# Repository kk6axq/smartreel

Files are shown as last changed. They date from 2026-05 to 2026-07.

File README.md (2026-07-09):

# SmartReel

SmartReel is a smart storage rack for reels of surface-mount electronic
components that works hand-in-hand with [InvenTree](https://inventree.org/),
an open-source inventory management system. The rack is built from one or more
**reel modules**, each a row of slots; every slot senses whether a reel is
present, has an addressable RGB LED to guide the operator, and can be widened by
pulling **dividers**. A touchscreen **HMI** mounted on the rack is the operator's
control panel — it talks to the rack hardware over RS485 and to InvenTree over
HTTPS. InvenTree stays the single source of truth for inventory; SmartReel
records *where* each reel physically lives and lights slots to guide pick and
put-away. The operator scans a reel, the rack lights up, and the inventory
updates itself.

## Project status & disclaimer

This project was developed with substantial AI assistance (using large language
models as a coding and documentation aid). The hardware, firmware, and plugin
have been built and run on real SmartReel hardware, and the core workflows have
been exercised on the bench and in use — but this is **not infallible software**.
It has not been through formal verification or a third-party audit, it almost
certainly contains bugs, and both the code and the docs may be incomplete or
occasionally wrong.

Treat it as a working reference design, not a turnkey product:

- Review the code yourself before relying on it, and read
  [`docs/known-bugs.md`](docs/known-bugs.md) for known limitations.
- **Security:** the HMI currently talks to InvenTree over HTTPS *without*
  certificate verification (`setInsecure()`), so the auth token is exposed to
  on-path attackers. Do not deploy on an untrusted network until certificate
  pinning is in place — see [`docs/known-bugs.md`](docs/known-bugs.md).
- It is provided as-is, with no warranty. You are responsible for validating it
  for your own use, especially anything safety- or inventory-critical.

Issues and pull requests that fix bugs or fill gaps are welcome.

## Repository layout

```
esp32-hmi/         ESP32-S3 touchscreen HMI firmware (C++ / PlatformIO / LVGL)
core-fw/           RP2040 core firmware that drives the reel modules (C++ / PlatformIO)
inventree-plugin/  InvenTree server-side plugin (Python)
pcbs/              KiCad hardware designs
  CorePCB/           Core PCB
  ReelPCB/           reel module PCB
debug-fw/          Bench/debug tooling (not shipped)
  mock-inventree/    FastAPI stand-in for the plugin, used during HMI development
  core-hwtest/       RP2040 hardware bring-up test
  esp32-rs485-pintest/ standalone ESP32 RS485 pin-toggle tool
  inject.py          bench event injector (drives the core test rig over USB)
  sd-assets/         mock QR codes for bench-testing the scan->resolve flow
docs/              Project documentation (start at docs/README.md)
labels/            Printable slot label PDFs (make_labels.py; PDFs git-ignored)
scripts/           Flashing, SD deployment, QR generation helpers
```

## Documentation

The full documentation set lives under [`docs/`](docs/README.md). Start with the
[documentation index](docs/README.md), then dive into the manual chapters:

- [Concept of Operations](docs/manual/01-concept-of-operations.md) — what SmartReel is and the end-to-end workflows.
- [Hardware Structure](docs/manual/02-hardware.md) — rack, Core PCB, reel modules, LEDs, sensors, wiring.
- [Software Structure](docs/manual/03-software-architecture.md) — components, subsystems, and system data flow.
- [API Reference](docs/manual/04-api-reference.md) — the HMI↔plugin HTTP API and the RS485 wire protocol.
- [InvenTree Integration](docs/manual/05-inventree-integration.md) — the plugin, install/config, and the sync model.
- [Operator User Manual](docs/manual/06-operator-manual.md) — task-oriented guide for shop-floor operators.

## Build & flash

**HMI firmware** (`esp32-hmi/`) and **Core firmware** (`core-fw/`) are
[PlatformIO](https://platformio.org/) projects. Build and flash:

```bash
# HMI (ESP32-S3) — requires manual boot mode (hold BOOT, tap RESET, release BOOT)
cd esp32-hmi && pio run
./scripts/flash-hmi.sh

# Core (RP2040) — UF2 dropped onto the BOOTSEL drive
cd core-fw && pio run
./scripts/flash-core.sh
```

The flash scripts locate the boards by USB VID, so the order they are plugged in
does not matter. See [`scripts/`](scripts/) for SD deployment (`deploy-sd.sh`)
and QR generation helpers.

**InvenTree plugin** (`inventree-plugin/`) is a Python plugin installed into an
InvenTree instance. See [`inventree-plugin/README.md`](inventree-plugin/README.md)
for installation, configuration, and the docker dev workflow.

**Mock server** — for HMI development without a live InvenTree, the FastAPI mock
at [`debug-fw/mock-inventree/`](debug-fw/mock-inventree/) serves the same HTTPS
contract as the plugin. See its [README](debug-fw/mock-inventree/README.md).

## Tests

Host-runnable tests (no hardware or InvenTree install needed) live under
[`tests/`](tests/README.md): the shared RS485 frame codec (`cd tests && make`)
and the plugin's pure service logic (`cd inventree-plugin && python3
test_services.py`). The full contract is exercised against a live InvenTree by
`inventree-plugin/test_live.py` and `test_multirack.py`.

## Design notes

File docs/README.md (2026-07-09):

# SmartReel Documentation

SmartReel is a smart electronics-component-reel storage rack that integrates
with [InvenTree](https://inventree.org/) for inventory management. An operator
stores reels of SMT components in physical slots; the rack tracks what is in
each slot, lights slots up to guide picking and put-away, and keeps inventory
in sync with InvenTree.

This directory is the documentation set for the whole project. It is written
against what the code actually does as of June 2026; where older design notes
disagree with the implementation, the implementation wins and the discrepancy
is called out.

## Documentation set (`docs/manual/`)

| Doc | What it covers |
|---|---|
| [Concept of Operations](manual/01-concept-of-operations.md) | What SmartReel is, who uses it, and the end-to-end workflows (commission, stock, pick, put-away, reconcile, firmware update). |
| [Hardware Structure](manual/02-hardware.md) | The rack, Core PCB, reel modules, ports/chaining, LEDs, sensors, HMI display, power, and RS485 wiring. |
| [Software Structure](manual/03-software-architecture.md) | Each software component, its subsystems and responsibilities, and a system-level data-flow diagram. |
| [API Reference](manual/04-api-reference.md) | The HMI↔plugin HTTP API (endpoints, auth, idempotency, rack identity) and the RS485 wire protocol (framing, message types, FW update). |
| [InvenTree Integration](manual/05-inventree-integration.md) | How the plugin works, installation/config, the op-queue + reconcile sync model, online/offline behaviour, and multi-rack. |
| [Operator User Manual](manual/06-operator-manual.md) | Plain-language, task-oriented guide for shop-floor operators using the HMI touchscreen. |

## Reference material (this directory)

These are the working documents the manual was built from. They remain useful
for detail and history but are not the authoritative manual:

- `hmi-plugin-api.md` — original API contract (superseded in detail by
  `manual/04-api-reference.md`, but still the canonical short-form contract).
- `smartreel-rs485-protocol.md` — original RS485 design note. Note its message
  catalog lists firmware messages under category `0xF_`; the **code implements
  them at `0x30`–`0x35`** (see API reference for why).
- `user-stories.md` — the behavioural source of truth for the workflows.
- `known-bugs.md` — open and fixed issues.

## Component layout (repository root)

```
esp32-hmi/         ESP32-S3 touchscreen HMI firmware (C++ / PlatformIO / LVGL)
core-fw/           RP2040 core firmware that drives the reel modules (C++ / PlatformIO)
inventree-plugin/  InvenTree server-side plugin (Python)
pcbs/              KiCad hardware designs
  CorePCB/           Core PCB
  ReelPCB/           reel module PCB
debug-fw/          Bench/debug tooling (not shipped)
  mock-inventree/    FastAPI stand-in for the plugin, used during HMI development
  core-hwtest/       RP2040 hardware bring-up test
  esp32-rs485-pintest/ standalone ESP32 RS485 pin-toggle tool
  inject.py          bench event injector (drives the core test rig over USB)
  sd-assets/         mock QR codes for bench-testing the scan->resolve flow
labels/            Printable slot label PDFs (make_labels.py; PDFs git-ignored)
scripts/           Flashing, SD deployment, QR generation helpers
```

> **In-progress areas.** Two features were being developed alongside this
> documentation: an HMI graphics/tearing refinement, and a plugin "locate"
> capability for the find-a-part flow. The find/locate behaviour is described
> in the ConOps and InvenTree sections but may still be evolving.
</content>
</invoke>

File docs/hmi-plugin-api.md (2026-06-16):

# SmartReel HMI ↔ InvenTree plugin API (v1)

Canonical contract between the SmartReel HMI and the SmartReel InvenTree
plugin. Two servers implement it:

- `inventree-plugin/` — the real thing, running inside InvenTree.
  Base URL: `https://<inventree-host>/plugin/smartreel`
- `debug-fw/mock-inventree/` — standalone FastAPI mock for bench development.
  Base URL: `https://<dev-host>:8443`

The HMI appends `/api/v1/<path>` to its configured base URL, so both
servers are reached identically. Behaviour is specified by
`docs/user-stories.md` — when this file and the user stories disagree,
the user stories win and this file is out of date.

## Conventions

- **Auth**: every endpoint except `GET /health` requires
  `Authorization: Token <token>`. The real plugin accepts InvenTree API
  tokens; the mock uses `SR_TOKEN` (default `dev-token`).
- **HTTPS only**: the HMI refuses to send the token over cleartext.
- **Idempotency**: every mutating request carries an `op_id` string
  (`hmi-<chip-id>-<millis>-<n>`). Servers cache `op_id → response` for
  ≥10 minutes and replay the cached response on retry.
- **Slot numbers are physical positions** (1..N). The HMI's logical
  slots (divider-combined) map to the anchor physical position of the
  reel. InvenTree models each physical slot as a structural
  sub-location of the rack location, so a part shows as e.g.
  "SmartReel Rack A / Slot 32".
- **Errors**: non-2xx with `{"detail": "<human-readable>"}`.

## Endpoints

### `GET /health` — liveness (no auth)

```jsonc
{ "ok": true, "server": "smartreel-plugin", "version": "0.2.0", "time": "..." }
```

### `POST /rack/register` — boot-time self-registration

```jsonc
// req
{ "n_slots": 64, "op_id": "..." }
// resp
{ "location_id": 42, "slot_locations": [ { "slot": 1, "location_id": 4201 }, ... ] }
```

Idempotent. Ensures the rack location and one sub-location per physical
slot exist; creates missing ones if `n_slots` grew.

### `GET /rack` — full rack snapshot

Used at boot to sync, and periodically for reconciliation (detecting
stock moved in InvenTree without a physical removal — user-stories.md
"Background: Inventree inventory locations").

```jsonc
{
  "location_id": 42,
  "n_slots": 64,
  "slots": [
    {
      "slot": 3,
      "location_id": 4203,
      "stock": {                  // null when logically empty
        "id": 1001,
        "qty": 5000,
        "batch": "B-241001",
        "barcode": "MOCK-PART-00001",
        "part": { "id": "R-10K-0805", "name": "RES 10kohm 1% 0805",
                  "pkg": "0805", "mfg": "Yageo" }
      }
    }, ...
  ],
  "pickjobs_available": 2,
  "locates": [                    // pending "light this slot" requests
    { "id": 7, "slot_num": 32, "part": "R-10K-0805",
      "part_name": "RES 10kohm 1% 0805", "stock_id": 1001,
      "at": "2026-06-13T12:00:00" }
  ]
}
```

The HMI owns physical truth (slot sensors); this snapshot is logical
truth. A slot that is logically empty but physically occupied means the
part was moved in InvenTree behind our back → the HMI lights that slot
and instructs the user to remove the reel (no inventory action on
removal — InvenTree already moved it).

`locates` carries pending **locate requests** (see "Locate from InvenTree"
below): each is a slot the HMI should light to draw attention to it. The
HMI lights `locates[].slot_num` and, once shown, acks the ids via
`POST /rack/locates/ack` so they don't re-appear on the next poll.

### `POST /barcode/resolve` — what did I just scan?

```jsonc
// req
{ "code": "<raw scanned string>", "op_id": "..." }
// resp
{
  "type": "stockitem" | "part" | "location" | "unknown",
  "stock": { ...same shape as rack snapshot stock, plus "slot_num": 3|0... },
  "part":  { ... },              // when type == "part"
  "message": "Unknown barcode"   // when type == "unknown"
}
```

The real plugin resolves through InvenTree's barcode framework, so any
QR InvenTree can print (StockItem labels included) resolves here, as do
custom codes linked to a stock item at receival (matched by barcode
hash). In practice most scans are InvenTree-generated StockItem QR
labels — supplier codes are often 1D/Datamatrix, which the SmartReel
scanner doesn't read.
`stock.slot_num` is non-zero when that stock item is already in a rack
slot ("already in slot N" UX).

### `POST /rack/slots/{n}/assign` — load a reel into a slot

```jsonc
// req
{ "stock_item_id": 1001, "op_id": "..." }
// resp
{ "slot": 3, "stock": { ... } }
// errors: 404 unknown slot/stock, 409 slot occupied
```

Transfers the stock item into the slot's sub-location (with audit
trail). If the item was in another rack slot, that slot is implicitly
freed. Completes user story 1 after the HMI detects physical placement.

### `POST /rack/slots/{n}/pick` — single pick (whole reel)

```jsonc
// req
{ "op_id": "...", "destination_id": null }   // destination optional
// resp
{ "slot": 3, "stock_id": 1001, "moved_to": 99 }
// errors: 404 unknown slot, 409 slot logically empty
```

**Whole-reel semantics** (user story 3): transfers the slot's
StockItem to `destination_id` if given, else the plugin's configured
Staging location. The slot is then logically empty. No quantity math —
the reel physically left the rack.

### `POST /rack/slots/{n}/clear` — reconcile a manual removal

```jsonc
// req
{ "op_id": "...", "reason": "anomaly:removed" }
// resp
{ "slot": 3, "stock_id": 1001, "moved_to": 98 }
```

For anomaly paths (reel yanked without a scan/pick). Stock moves to the
configured "Unsorted / pulled" location so it isn't lost. 2xx even if
the slot was already logically empty (idempotent goal state).

### `POST /rack/locates/ack` — acknowledge consumed locate requests

```jsonc
// req
{ "ids": [7, 8] }        // ack these ids; {} or {"ids": []} clears the queue
// resp
{ "locates": [ ...remaining locate requests... ] }
```

Drains locate requests the HMI has lit (see "Locate from InvenTree").
Idempotent by construction: acking an unknown/already-acked id is a no-op.

### `GET /pickjobs` — list pick jobs

Jobs are created in InvenTree from build orders (plugin panel "Send to
SmartReel" on the Build Order page — user story 4).

```jsonc
{
  "jobs": [
    {
      "id": "BO-0042",
      "name": "PCB-Rev-A x 5",
      "requested_at": "2026-06-11T14:02:00Z",
      "status": "pending" | "partial" | "done",
      "destination_id": 99,            // staging unless overridden at send time
      "items": [
        {
          "idx": 0,
          "part_id": "R-10K-0805",
          "part_name": "RES 10kohm 1% 0805",
          "qty": 250,                  // required qty, informational on the HMI
          "picked": false,
          "located_slots": [3, 17]     // rack slots currently holding this part
        }, ...
      ]
    }, ...
  ]
}
```

- An **item** is one part. The HMI lights `located_slots` for all
  unpicked items; removing a reel of that part from any lit slot picks
  the item (one reel per item).
- `status` is **derived server-side**: `pending` (nothing picked),
  `partial` (some picked), `done` (all picked). The HMI's cancel button
  is purely local — already-picked items stay picked and the job shows
  `partial`, resumable later (user story 4, partial-pick paragraph).
- Items whose part is not in the rack have `located_slots: []`; the HMI
  shows them as unfulfillable rather than hiding them.

### `POST /pickjobs/{id}/items/{idx}/pick` — pick one job item

```jsonc
// req
{ "slot_num": 3, "op_id": "..." }
// resp
{ "item": { ...updated item... }, "job_status": "partial" | "done" }
// errors: 404 job/item/slot, 409 slot doesn't hold the item's part,
//         409 item already picked
```

Validates the slot holds the item's part, performs a whole-reel pick to
the job's destination, marks the item picked.

### `POST /anomaly` — report sensor-detected anomalies

```jsonc
// req
{ "kind": "removed" | "added" | "divider",
  "slot_num": 12, "detail": "free text", "op_id": "..." }
// resp
{ "id": 7, "logged": true }
```

Audit log on the server side (the real plugin attaches a note/history
entry). Inventory correction is separate (`/clear`).

### `GET /parts/locate?part_id=R-10K-0805`

```jsonc
{ "part_id": "R-10K-0805", "slots": [3, 17] }
```

Powers "find this part" independent of pick jobs.

## Locate from InvenTree (web-UI "locate" button → light a slot)

InvenTree's web UI has a **locate** button on StockItem and StockLocation
pages. The plugin implements InvenTree's `LocateMixin`
(`locate_stock_item` / `locate_stock_location`); InvenTree offloads the
call to a background worker, and the plugin — which has no direct link to
the rack — records the request as a pending locate on the owning rack and
lets the HMI light the slot. Flow:

```
InvenTree "locate" button
  → POST /api/plugin/locate/   (InvenTree core)
  → offload_task → SmartReelPlugin.locate_stock_item / _location  (worker)
  → resolve item/location → (rack, physical slot_num)
  → enqueue locate on the rack's metadata
        │
HMI  ── GET /rack (its existing poll) ──► sees `locates: [{id, slot_num,…}]`
  → lights slot_num
  → POST /rack/locates/ack {ids:[…]}  ──► request drained
```

- `locate_stock_item(item_pk)`: if the item is in stock and homed in a
  rack slot, queues that slot (carrying the part/stock context).
- `locate_stock_location(location_pk)`: if the location is a rack **slot**,
  queues that slot; if it's a **rack** itself, queues every occupied slot;
  locations outside any SmartReel rack are a no-op (some other plugin owns
  them).
- A locate for an already-queued slot **refreshes** it (no duplicate
  stacking); the queue is capped (50) and stored on the rack location's
  `metadata['smartreel_locates']`.
- Locate requests are **not** op_id-idempotent (they originate inside
  InvenTree, not from the HMI); the HMI side is made safe by `ack`'s set
  semantics and by the per-slot dedupe.

## Provisioning (how the HMI gets its URL + token)

Typing on the HMI is painful, so credentials are delivered by QR code
using the scanner that's already on the unit:

1. In InvenTree, the SmartReel plugin settings panel shows a **setup
   QR code** (and a button to regenerate it / revoke the old token).
   The token is an InvenTree API token issued for a dedicated machine
   user, so SmartReel access can be revoked independently.
2. On the HMI: Settings → Network → "Scan setup code" → scan the
   screen. The HMI parses the payload, stores URL + token in
   `config_store`, and immediately runs `GET /health` to confirm.

QR payload (one line of text):

```jsonc
SRPROV1:{"u":"https://inventree.example/plugin/smartreel",
         "t":"inv-token-...",
         "f":"AB:CD:..."}   // optional TLS cert SHA-256 fingerprint
```

- `SRPROV1:` prefix distinguishes a provisioning code from a part
  barcode (and versions the payload).
- `u` is the plugin base URL (HMI appends `/api/v1/...`).
- `f` is optional; when present the HMI may pin the server cert
  instead of blind-trusting it. Ignored by firmware that doesn't pin.

The mock prints an equivalent QR/payload from its dashboard so bench
provisioning works the same way.

## Plugin settings (real plugin)

| Setting | Meaning |
|---|---|
| Rack location | structural location representing this SmartReel unit |
| Staging location | default destination for picked reels |
| Pulled location | destination for anomaly `/clear` removals |

## Multiple SmartReel units

Supported. One InvenTree instance drives many independent racks, and the
HMI/wire protocol is unchanged because each unit's identity rides on its
API token.

- Each rack is its own `StockLocation` tagged
  `metadata['smartreel'] = { "is_rack": true, "staging"?, "pulled"? }`;
  slots are child locations tagged `{"slot": n}`.
- **The token carries the rack.** Provisioning (`GET /provision?location=
  <pk>`) tags the location a rack and binds the issued `ApiToken` via
  `token.set_metadata('smartreel_rack', <loc_pk>)`. Every rack-scoped
  request resolves its rack from `request.auth`; an unbound token is
  refused with 409 (re-provision). There is no global "rack location"
  setting and no shared-rack fallback — every unit, including the first,
  is provisioned from its location page.
- `/health` and `/barcode/resolve` are rack-independent (resolve only
  uses the rack to fill `slot_num`).
- Pick jobs store a target rack pk; `GET /pickjobs` and `located_slots`
  are scoped to the requesting token's rack. A build can carry **one job
  per rack**: the panel lists candidate reels (`GET /pickjobs/options`) and
  `POST /pickjobs/from-build` takes `stock_ids`, grouping the selected reels
  by the rack that holds them (each item pinned to its `stock_id`).
  `GET /pickjobs?all=1` (session) lists every rack's jobs for the panel, and
  `GET /racks` lists configured racks.
- The provisioning panel appears on every stock-location page.
  `STAGING_LOCATION` / `PULLED_LOCATION` are instance-wide defaults a
  rack may override in its own metadata.

## Changelog

- **2026-06-15**: review-feedback round. Added `GET /rack/occupancy` (cheap
  fingerprint for ~10s move detection) and `GET /pickjobs/options` (candidate
  reels per BOM line). `POST /pickjobs/from-build` now takes `stock_ids` and
  fans out **one job per rack** (each item pinned to a `stock_id`) instead of a
  single `rack_location_id` job; `DELETE /pickjobs/{id}` clears all of a build's
  rack jobs.
- **2026-06-13**: LocateMixin support — InvenTree's web-UI "locate" button
  (StockItem / StockLocation) now lights the slot on the physical rack.
  Locate requests ride on the `GET /rack` snapshot (`locates`) and are
  drained by `POST /rack/locates/ack`. Mock gains a `POST /_dev/locate`
  helper to simulate the button.
- **2026-06-13**: multiple racks implemented — rack identity is bound to
  the HMI's API token; the global `RACK_LOCATION` setting and single-rack
  fallback are removed. Added `/racks`, `rack_location_id` on
  `from-build`, and `/pickjobs?all=1` for the panel.
- **2026-06-11**: rewritten against `docs/user-stories.md`. Picks are
  whole-reel transfers (qty decrement model removed); pick jobs come
  from build orders with derived `pending/partial/done` status; rack
  snapshot doubles as the reconciliation source; `destination_id`
  per job/pick.

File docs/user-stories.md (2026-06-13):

# User Stories
This doc explains how Smart Reel is going to be used. The goal is that this will help hone the direction of development.

## Background
The user uses Inventree to manage electronic components for PCB Assembly in a small to medium sized business or hobby environment. They use Inventree to streamline inventory management, and use plugins to automate monotonous tasks. For the sake of SmartReel, we're mostly concerned with reels of SMT components. Each reel in their library is individually labelled with a QR code that's associated with the Inventree StockItem.

## Background: Inventree inventory locations
Each SmartReel instance is configured as a structural inventory location in Inventree. Each slot is a sub location of the parent reel location, and when parts are stored, they are transferred into slot locations. This way, a user can lookup a part and see that it's in "SmartReel Rack A, Slot 32."

It's possible (though not recommended) that a part could be moved in Inventree without being removed from SmartReel first. If this happens, the SmartReel should alert the user so that the next time a user is present, the offending part(s) can be manually removed. This would work by lighting up the offending parts and instructing the user to remove them.

## Use case 1: storing parts
When the user receives new parts they've ordered, they inventory them into Inventree. This gets them into inventory, but they need to be properly stored. To do this, they walk up to the SmartReel HMI, then scan the reel's QR code, or clicks the load button on the screen and scans the QR code on the reel.

When this happens, the SmartReel instance uses its connection to Inventree via the SmartReel plugin to get basic info about the part, showing on the screen the name of the part and the current qty. It then follows the loading flow to direct the user to load it into a slot (see the loading flow section). Once placed, it moves that StockItem in Inventree to be housed in that slot location.

## Use case 2: browsing parts
The HMI has a view screen that lets you scroll through parts that are in the SmartReel unit. Each entry has a find button that when pressed lights up the LEDs for that slot for a period of a few seconds. There is also a pick button that triggers a single pick action.

## User case 3: single part picking
When a user wants to retrieve a single reel from SmartReel, they go to the view screen, find the part in the list, then click pick. The system then lights up the LED corresponding to that part's location. At any time prior to the part being removed the user can cancel the action by clicking a cancel button on the HMI. Once the user picks up the reel, the button is no longer pressed, and the system registers the inventory removal. This causes the reel StockItem to be transferred to a predetermined inventory location, i.e. "Staging" in Inventree. This location is configured in the Inventree plugin. Once complete, it turns off the LED and the slot is now logically empty.

## User case 4: job picking
When the user has a build order for parts in Inventree, they can open the SmartReel plugin and send a pick job. This basically provides the smart reel unit a "job" which is a series of parts that need to be picked. The user can then go to the jobs screen in the HMI, select the job, and the unit will light up all the parts that need to be picked. Once all the parts are picked, the job is complete and all the parts are transferred (to the staging location or another specificed location).

If the user only picks some of the parts, or none of the parts, and presses the cancel button, then only the parts (if any) that were removed are moved in inventory. The user can come back to finish the pick job later (it should show partially picked).

## SmartReel hardware
SmartReel is composed of reel modules. These have a button for each slot that is pressed whenever a reel is present in the slot. Additionally there are dividers that can be removed to make slots wider, to accomodate larger reels. Each divider has a button that is pressed when the divider is present. This allows SmartReel to automatically know the width of slots (single width, double, multi, etc), and the presence of parts. Each slot also has an addressable RGB led. This is used to indicate slot status during various actions. When a composite slot is formed, all of the LEDs for the individual slots in that group all follow the same state together. Like if a slot needs to light up red and there's three slots in the composite slot, all three LEDs should be red.

## SmartReel Loading
This details exactly how loading works from a user interaction perspective. Once the HMI is ready to load, it lights up the LEDs for any slots that are not currently occupied. These are potential locations for the user to place the part. The user can cancel the loading operation at any time prior to inserting the parts by clicking cancel on the HMI. Once they place the reel of parts into a slot, the HMI detects the button being pressed and registers that location as the location of that part. The part is now "placed" and the loading action is complete, and inventory records can be updated.

## Internet connectivity
The HMI needs internet connectivity to connect to Inventree and the SmartReel plugin. If internet is not present, the user should be warned, and we should try to re-establish a connection. For now, we won't support picking if access to Inventree isn't available, to prevent the Smartreel from getting out of sync with Inventree.

## UI Updates
A last few notes on improving the UI.
The current screen has very small font. It's only a 4.3" screen, so we should prioritize less, larger font size text. The current reel occupancy grid that takes up the top 1/3 of the home screen should move to its own screen. We should try to keep all font sizes at least as large as what we have for the main card titles on the home screen. The current small font size is too small.

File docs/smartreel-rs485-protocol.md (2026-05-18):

# SmartReel RS485 Protocol & Firmware Update Design
SmartReel — Project Context
A modular system of "smart reels" managed from a touchscreen HMI. Each reel module has addressable LEDs and a row of inputs; the HMI controls the lighting and reacts to input events.
Hardware architecture
Three boards, one cable run:

HMI — ESP32 with touchscreen + SD card. Acts as RS485 bus master. User interface, configuration storage, firmware images for the core, any network connectivity.
Core PCB — RP2040 or RP2350 ("Pico"). Talks to up to 4+ reel modules. Hosts the RS485 transceiver (SP3485), 3.3V↔5V level shifters (74AHCT244 / 74LVC244), and a 12V→5V buck for the reel rail.
Reel modules — pluggable. Each carries WS2812B LEDs, a 74HC165 PISO shift register for inputs, and a sense resistor/ID network read by the core's ADC.

ESP32 HMI ↔ RP2040/RP2350 core, RS485 link, four reel modules with WS2812B LEDs and PISO shift registers.

## Frame format

Length-prefixed frame with CRC-16. Avoids the timing dependencies of Modbus RTU and is easier to debug:

```
+------+------+------+------+------+------+------+--------------+------+------+
| 0xAA | 0x55 | LEN_H| LEN_L| ADDR | SEQ  | TYPE | PAYLOAD ...  | CRC_H| CRC_L|
+------+------+------+------+------+------+------+--------------+------+------+
```

- **0xAA 0x55** — sync bytes; receiver hunts for these to resync after a glitch.
- **LEN** — number of bytes from ADDR through end of PAYLOAD (excludes sync and CRC). 16-bit lets you do larger firmware chunks comfortably.
- **ADDR** — slave address (0x01 for the core; reserve 0x00 broadcast, 0xFF for the ESP32-as-master). Useful if you ever bus more than one core, or for a "scan for devices" probe.
- **SEQ** — sequence number; a response echoes the request's SEQ so the ESP32 can match them and detect retransmits.
- **TYPE** — high nibble = category (0=system, 1=reel I/O, 2=LED, 3=config, 8=async event, F=firmware update); low nibble + payload define the specific command. Lets you parse/dispatch by category cheaply.
- **CRC-16/CCITT** over ADDR..end-of-PAYLOAD. CRC-16/CCITT-FALSE (poly 0x1021, init 0xFFFF) is fine and trivially available on both sides.

Replies use the same TYPE byte with bit 7 set (so 0x10 request → 0x90 response), with bit 6 indicating error (so 0xD0 = error response). That makes the wire trace readable without a decoder table.

## Application message catalog

### System (TYPE 0x0_)

| Code | Name | Dir | Payload |
|---|---|-----|---|
| 0x00 | PING | E→P | none → echo |
| 0x01 | GET_VERSION | E→P | none → fw_major, fw_minor, fw_patch, build_id (4B), hw_rev |
| 0x02 | GET_STATUS | E→P | none → uptime_s (4B), reels_present (bitmap), error_flags (2B) |
| 0x03 | RESET | E→P | reason byte (0=normal, 1=enter_update_mode) |
| 0x04 | POLL | E→P | none → "no events" or up to N queued events |

### Reel I/O (TYPE 0x1_)

| Code | Name | Dir | Payload |
|---|---|-----|---|
| 0x10 | GET_REEL_INFO | E→P | reel_id (or 0xFF for all) → presence, sense_mv (2B per reel), eeprom/ID bytes |
| 0x11 | READ_INPUTS | E→P | reel_id → PISO bytes (whatever your shift register reads) |
| 0x12 | SET_POLL_RATE | E→P | reel_id, rate_hz (2B) — how often the Pico samples PISO |

### LED control (TYPE 0x2_)

| Code | Name | Dir | Payload |
|---|---|-----|---|
| 0x20 | SET_REEL_PIXELS | E→P | reel_id, start_idx, count, R,G,B,R,G,B,... |
| 0x21 | FILL_REEL | E→P | reel_id, R, G, B |
| 0x22 | SET_BRIGHTNESS | E→P | reel_id (or 0xFF), brightness (0–255) |
| 0x23 | SET_ANIMATION | E→P | reel_id, anim_id, params... (chase, pulse, etc — runs locally on Pico) |
| 0x24 | COMMIT | E→P | reel_bitmap — atomic show of staged pixel data across multiple reels |

The COMMIT pattern is worth doing: SET_REEL_PIXELS writes to a back-buffer, COMMIT flips and calls `show()` across all selected reels in the same frame. Otherwise your reels visibly tear when updating more than one at a time over a slowish bus.

### Async events (TYPE 0x8_, Pico → ESP32, no response expected)

| Code | Name | Payload |
|---|---|---|
| 0x80 | INPUT_CHANGE | reel_id, prev_state, new_state, timestamp_ms (4B) |
| 0x81 | REEL_INSERTED | reel_id, sense_mv (2B), ID bytes |
| 0x82 | REEL_REMOVED | reel_id |
| 0x83 | SENSE_THRESHOLD | reel_id, sense_mv, threshold_id |
| 0x8F | LOG | level, ASCII message |

Events are fire-and-forget — but the ESP32 should NAK with an "unknown SEQ" if it gets a spurious one, so the Pico knows the link is alive. Pico keeps a small ring buffer of unACK'd events and resends after a timeout; mark them with a sequence number the ESP32 echoes back in an ACK frame.

This is important: **on a half-duplex RS485 link, the Pico cannot transmit whenever it wants**. The ESP32 is bus master. So async events have to be either (a) returned in the response slot of the next poll, or (b) signaled via a dedicated "any events pending?" poll the ESP32 issues regularly. The simplest pattern: the ESP32 issues `POLL` (0x04) every ~20ms, and the Pico's response is either "no events" or up to N queued events. Higher-priority button events should keep latency under ~50ms; this poll rate gets you there.

## Firmware update

Run a custom bootloader on the Pico and lay out flash as A/B slots so you always have a known-good fallback.

### Flash layout (RP2040, 2 MB)

```
0x10000000  Bootloader            (32 KB)
0x10008000  Metadata block        (4 KB, two copies for wear)
0x1000A000  App Slot A            (~1000 KB)
0x10104000  App Slot B            (~1000 KB)
0x101FE000  Reserved / config     (8 KB)
```

On RP2350 (4 MB) you have headroom to make each slot 1.5 MB and add a scratch staging area if you want, but the A/B pattern is the same.

### Metadata block

Contains: active slot, pending slot, image size, SHA-256, version, boot count, "needs confirm" flag. Write two copies and pick the one with the higher monotonic counter — cheap protection against power-loss during update.

### Bootloader logic

On reset, read metadata, pick the slot marked active, verify its hash if `needs_confirm == true`, jump to it. If the previously-booted slot failed to clear the `needs_confirm` flag within N boots, revert to the other slot. This is the rollback guarantee.

### Update flow over RS485

| Step | Message | Notes |
|---|---|---|
| 1 | `FW_BEGIN` | ESP32 sends total_size (4B), SHA-256 (32B), version (4B). Pico picks inactive slot, erases it (this takes a few seconds — respond with `BUSY` until done, then `READY`). |
| 2 | `FW_CHUNK` × N | offset (4B) + data (up to ~512B per frame). Pico writes to flash, ACKs with the offset it last wrote. ESP32 retries any unACK'd chunk. |
| 3 | `FW_VERIFY` | Pico re-reads the slot, hashes it, compares to the announced hash. Returns OK or hash-mismatch. |
| 4 | `FW_COMMIT` | Pico writes metadata: pending=new_slot, needs_confirm=true. ACKs, then issues itself a reset. |
| 5 | Bootloader runs | Sees pending slot, boots it, sets boot_count++. |
| 6 | New app boots | Sends `FW_BOOTED` event to ESP32. ESP32 sends `FW_CONFIRM`, which clears `needs_confirm`. Without this confirm within a deadline, next reset reverts to the previous slot. |

The confirm-after-boot step is what saves you when the new firmware boots but is broken in a way that crashes before it can talk to the HMI — you ship a unit, update over the wire, the new firmware has a bug that bricks RS485, and on the next power cycle the bootloader rolls back automatically.

### Practical numbers

- At 115200 baud, raw throughput is ~11 KB/s; a 500 KB image takes ~50 s plus erase/verify overhead. Bump to 921600 baud (SP3485 handles it fine over short cable runs) and you're at ~6 s.
- Chunk size: 256 B is the RP2040 flash page size. Send one or two pages per RS485 frame so the Pico can write a whole page without buffering. With 512 B chunks + framing overhead, you get ~80% bus efficiency.
- During update, suspend reel polling and LED animations — the Pico shouldn't be doing PIO work while it's erasing flash anyway (XIP is disabled, interrupts off).

### Entering update mode

Two options:

1. The running app handles `FW_BEGIN` itself (writing to the *other* slot while it runs from its own), which is the smoothest UX.
2. The ESP32 sends `RESET` with reason=enter_update_mode, the bootloader sees a flag in metadata, and runs a minimal RS485 update handler instead of jumping to the app.

The first is preferable because the user gets reel functionality up until the moment of commit; the bootloader fallback is your insurance for when the app is too broken to even handle FW messages.

One last thing — keep the bootloader *small* and *boring*. No reel logic, no LEDs, no animations. Just RS485 receive, flash write, metadata, jump. That bootloader is the thing you can never field-update, so it has to be obviously correct.

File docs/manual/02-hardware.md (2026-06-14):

# SmartReel — Hardware Structure

This describes the physical/electrical structure of a SmartReel rack. Details
come from the firmware configuration, board READMEs, and the KiCad project file
names; where a value couldn't be confirmed from text sources it is marked TODO.

## 1. Overview

A rack is three kinds of board on one cable run:

```
  +-----------------------+        +------------------+        +-----------------------------+
  |  HMI                  |        |  Core PCB        |        |  Reel modules (per port)    |
  |  ESP32-S3 +           | RS485  |  RP2040/RP2350   | ports  |  WS2812B LEDs               |
  |  4.3" RGB touchscreen |<------>|  bus slave       |<======>|  74HC165 input registers    |
  |  + SD card            |        |  bus master-side |  0..3  |  slot + divider buttons     |
  |  (RS485 master)       |        |  to modules      |        |  sense/ID resistor network  |
  +-----------------------+        +------------------+        +-----------------------------+
```

- The **HMI** is the RS485 bus master and the user interface.
- The **Core PCB** is the RS485 slave; it drives up to 4 ports of reel modules.
- **Reel modules** are pluggable and chain off each port (up to 4 deep).

Capacity ceiling: **4 ports × 4 modules/port × 16 slots/module = 256 slots**.

## 2. HMI — ESP32-S3 touchscreen

Board: **Waveshare ESP32-S3-Touch-LCD-4.3B**.

| Item | Detail |
|---|---|
| MCU | ESP32-S3-WROOM-1-N16R8 (16 MB flash, 8 MB PSRAM), 240 MHz |
| Display | 4.3", 800×480, 16-bit RGB565 parallel (DPI), ST7262-class timing |
| Pixel clock | 16 MHz (12 MHz causes a stuck-white panel on this board — do not lower) |
| Touch | GT911 capacitive, I²C (addr 0x5D/0x14), INT on GPIO4 |
| I/O expander | CH422G on I²C (addr 0x24) — drives LCD reset, backlight, touch reset, USB select |
| Storage | microSD via SDMMC, **1-bit** mode (CMD GPIO11, CLK GPIO12, D0 GPIO13) |
| RS485 | UART, **auto-direction** transceiver — TX GPIO44, RX GPIO43, no DE pin |
| I²C bus | SDA GPIO8, SCL GPIO9, 400 kHz (shared by GT911, CH422G, optional QR scanner) |
| QR scanner | optional I²C device (addr 0x0C); if absent the HMI falls back to manual entry |

RGB LCD pin map (from `esp32-hmi/src/board/board_pins.h`):

```
HSYNC GPIO46   VSYNC GPIO3   DE GPIO5   PCLK GPIO7
R[0..4] GPIO 1,  2, 42, 41, 40
G[0..5] GPIO 39, 0, 45, 48, 47, 21
B[0..4] GPIO 14, 38, 18, 17, 10
```

The display uses **two framebuffers in PSRAM** (~768 KB each, ~1.5 MB total)
for tearing-free refresh; see [Software Architecture](03-software-architecture.md#display).

> **RS485 direction asymmetry.** The HMI side uses a hardware *auto-direction*
> transceiver (no driver-enable GPIO), and the firmware caps the link at
> **115200 baud** because the auto-direction RC switch cannot turn the line
> around fast enough for higher rates. The Core side (below) uses a discrete DE
> pin. Both ends run 115200.

## 3. Core PCB

KiCad project: `pcbs/CorePCB/SmartReelCore/`.

| Function | Part / detail |
|---|---|
| MCU | Raspberry Pi Pico class — **RP2040 or RP2350** |
| RS485 transceiver | SP3485 (half-duplex) with a discrete DE/RE# line |
| Level shifting | SN74AHCT244 / 74LVC244 (3.3 V ↔ 5 V) for the module signals |
| Module rail | 12 V → 5 V buck converter feeding the reel modules |
| Sense ADC | ADS1115 (16-bit I²C, 4 channels — one per port) for module detection |

Core pin assignments (from `core-fw/src/config.h`):

```
RS485:   TX GP16 -> SP3485 DI     RX GP17 <- SP3485 RO     DE GP18 -> SP3485 DE+RE#
RS485 baud: 115200
LED data (NeoPXL8): GP6, GP7, GP8, GP9  (ports 0..3)
Shift registers (74HC165), shared:  clock GP10,  latch/PL# GP11 (active LOW)
Shift-register data in, per port:   GP12, GP13, GP14, GP15
Sense ADC: ADS1115 on I²C0 (SDA GP0/SCL GP1 area — TODO confirm exact I²C pins), addr 0x48
Debug LED: GP2 (RS485 link health)
```

The Core is RS485 slave address **0x01**. It declares the link "up" only while a
valid master frame has arrived within the last 1000 ms.

## 4. Reel modules

KiCad project: `pcbs/ReelPCB/` (with a `Switch_Unit.kicad_sch` sub-circuit and
per-module label PDFs under `labels/`).

Each module provides **16 reel slots** and carries:

- **16 WS2812B addressable RGB LEDs** — one per slot, daisy-chained. Driven from
  the Core via NeoPXL8 (PIO + DMA, 8 parallel data lines, 800 kHz, GRB order).
- **Inputs via 74HC165 PISO shift registers** — **32 input bits per module**:
  - 16 **slot-present** bits (a button pressed while a reel sits in the slot), and
  - 16 **divider** bits (a button pressed while the divider to the *right* of a
    slot is installed).
  - Logical bit order per module is `D0 S0 D1 S1 … D15 S15`. (The raw hardware
    clocks slots out reversed within each shift-register byte; the Core firmware
    descrambles them, so the rest of the system sees the clean order.)
- **Sense / ID resistor network** — a per-module pull-down that the Core reads on
  that port's ADS1115 channel to count how many modules are chained.

### Dividers and slot width

Dividers between slots are removable. Pulling the divider between two slots
merges them into one wider logical slot (for a larger reel). Because each
divider has a sense bit, the rack automatically knows the width of every slot.
When several physical slots form one composite slot, all of their LEDs follow
the same colour/state together.

### Module-count detection

Each inserted module adds a 10 kΩ pull-down in parallel against a 2.2 kΩ
pull-up to 3.3 V, so the rail voltage on a port quantises by module count. The
Core firmware maps the measured millivolts to a module count (0–4):

| Modules | Approx. sense (mV) |
|---|---|
| 0 (open) | 3300 |
| 1 | 1458 |
| 2 | 989 |
| 3 | 732 |
| 4 | 579 |

A change must hold for 2 consecutive samples before the Core emits a
`REEL_INSERTED`/`REEL_REMOVED` event.

## 5. Ports and chaining

- The Core has **4 ports** (0–3). In the protocol, `reel_id` **is the port
  number**.
- Each port carries one LED data line, one shift-register chain (shared clock +
  latch, per-port data line), and one sense channel.
- Up to **4 modules chain per port**. Within a port, module `m` owns LED pixels
  `[m*16, m*16+16)` and input bits `[m*32, m*32+32)`.
- The HMI labels ports as "chains" 1–4 in the UI.

## 6. Power

- **12 V** input is the main rail. The Core PCB bucks it to **5 V** for the reel
  module rail (LEDs + logic). Reel modules use 5 V and 3.3 V (3.3 V generated on
  the Core / modules — TODO confirm exact per-module regulation).
- **HMI power**: the Waveshare board is typically powered over USB-C or a 5 V
  input. The exact rack-integration power source is TODO (not documented in the
  source tree).

## 7. RS485 wiring

A single RS485 pair runs between the HMI (master) and the Core (slave). The Core
fans the reel modules out over its ports; the module signals (LED data,
shift-register clock/latch/data, sense) are *not* RS485 — they are local
parallel/serial lines level-shifted on the Core PCB. Only the HMI↔Core link is
RS485.

- Master address `0xFF`, Core address `0x01`, broadcast `0x00`.
- 115200 baud, half-duplex. The HMI polls the Core every ~20 ms so button
  events reach the UI within ~50 ms.

See the [API Reference](04-api-reference.md#part-b-rs485-wire-protocol) for the
full frame format and message catalog.

## 8. Supporting artifacts in the repo

- `labels/` — printable slot-label PDFs (one per module, slots numbered).
- `scripts/` — flashing, SD deployment, and mock-QR generation helpers.
- `debug-fw/inject.py` — bench event injector for the RP2040 core test rig.
- `debug-fw/sd-assets/` — mock QR codes for bench-testing the scan flow.
- `pcbs/CorePCB/`, `pcbs/ReelPCB/` — the KiCad designs (schematics, PCB, production
  outputs under each project's `production/`).

## 9. Known hardware TODOs

- Exact ADS1115 I²C pin assignment on the Core (config comment vs. board).
- Per-module 3.3 V regulation source.
- HMI power input in the final rack integration.
- Real-hardware validation of the module-count sense thresholds.
</content>

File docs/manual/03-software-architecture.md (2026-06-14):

# SmartReel — Software Architecture

Four software components make up SmartReel. Two run on the rack (the HMI and
Core firmware), one runs inside InvenTree (the plugin), and one is a development
stand-in for the plugin (the mock).

## 1. System-level data flow

```mermaid
flowchart LR
    subgraph Rack
        HMI["ESP32-S3 HMI firmware<br/>(C++ / LVGL)"]
        CORE["RP2040 Core firmware<br/>(C++)"]
        MODS["Reel modules<br/>LEDs + sensors"]
    end
    subgraph Server
        PLUGIN["SmartReel plugin<br/>(Python, inside InvenTree)"]
        INV["InvenTree core<br/>StockItems / Locations / Builds"]
    end
    MOCK["debug-fw/mock-inventree<br/>(FastAPI, dev only)"]

    HMI <-->|"RS485 framed protocol<br/>115200 baud, half-duplex"| CORE
    CORE <-->|"LED data + shift-reg inputs + sense"| MODS
    HMI <-->|"HTTPS /api/v1/*<br/>Token auth, op_id idempotency"| PLUGIN
    PLUGIN --> INV
    HMI -.->|"same HTTPS contract<br/>(bench dev)"| MOCK
```

Two protocols, two boundaries:

- **HMI ↔ Core**: a custom length-prefixed, CRC-16 framed protocol over RS485.
  The HMI is master and polls the Core; the Core reports sensor events and
  drives the LEDs. See [API Reference, Part B](04-api-reference.md#part-b-rs485-wire-protocol).
- **HMI ↔ InvenTree**: a workflow-shaped HTTPS API (`/api/v1/*`) with Token
  auth and `op_id` idempotency. The plugin (or the mock) serves it. See
  [API Reference, Part A](04-api-reference.md#part-a-hmi--plugin-http-api).

## 2. ESP32-S3 HMI firmware (`esp32-hmi/`)

C++ on PlatformIO (pioarduino / IDF 5.3), LVGL 8.4, ArduinoJson 7. Source is
organised by subsystem under `src/`.

### Subsystems

| Subsystem | Responsibility |
|---|---|
| `app/` | Application state and logic: logical-slot model, hardware mirror, LED orchestration, and the InvenTree sync engine. |
| `board/` | Pin map (`board_pins.h`) and the CH422G I/O-expander driver. |
| `display/` | RGB LCD driver and the tearing-free framebuffer pipeline. |
| `touch/` | GT911 capacitive touch driver → LVGL input device. |
| `sensors/` | Optional I²C QR scanner. |
| `rs485/` | RS485 master: frame codec, CRC-16, transactions, background poll. |
| `fw/` | Firmware update: HMI self-OTA from SD, and Core OTA over RS485. |
| `net/` | WiFi manager and the `inv_api` HTTPS client to InvenTree. |
| `storage/` | `config_store` (settings/credentials) and `state_store` (slot contents, jobs) on SD. |
| `ui/` | LVGL screens, the app-state model, screen manager, theme. |
| `util/` | Helpers, including marshalling work onto the LVGL task. |

### Key modules

**`app/inv_sync`** — owns *all* InvenTree traffic. A worker task
(`inv-sync`, priority 1, pinned to APP_CPU) runs a:

- **Health poll** — every 15 s while online, 5 s while offline; sets
  `app_state.online`. "Online" means the last good health check is younger than
  45 s.
- **Rack register** on first successful contact.
- **Reconcile** — `GET /rack` every 60 s and on demand; compares server truth
  to physical sensors (see [ConOps §4.5](01-concept-of-operations.md#45-inventory-reconcile-background)).
- **Pick-job fetch** on demand (throttled ~10 s).
- **Op queue** — a 16-deep retrying queue of mutations (`Assign`, `Pick`,
  `JobPick`, `Clear`, `Anomaly`). Each op carries a unique `op_id`; the queue
  retries up to 20 attempts. A `4xx` is a permanent reject (logged; the next
  reconcile catches any drift). Idempotency makes retries safe.

**`app` state & slot model** (`ui/app_state.h`, `app/slot_map`, `app/hw_mirror`):

- `hw_mirror` is the live cache of per-port module counts and per-module 32-bit
  input words, fed by RS485 poll events.
- `slot_map` is pure logic that turns module counts + divider bits into
  **logical slots**: runs of physical slots merged across pulled dividers,
  numbered by the lowest physical position in the run.
- `app_state` holds the current logical rack (slot → part/qty/state). States:
  `EMPTY`, `OCCUPIED`, `TARGET` (lit for an action), `PICKED`, `WARN`, `ERROR`.
- **Commissioning**: before commit the rack follows live hardware; after commit
  (`rack.committed`) the HMI validates live hardware against the committed
  layout and raises anomalies on deviation.

**`net/inv_api`** — the HTTPS client (details in
[API Reference](04-api-reference.md)):

- Appends `/api/v1/<path>` to the configured base URL.
- **HTTPS-only**: `build_url()` refuses any non-`https://` URL, so the token
  never crosses the wire in cleartext.
- Sends `Authorization: Token <token>`.
- Generates op_ids of the form `hmi-<chip-id>-<millis>-<n>`.
- 4 s request timeout, 2 s connect timeout. Calls are blocking; callers run them
  on a worker task and marshal results back to the LVGL task.
- TLS currently uses `setInsecure()` (self-signed mock); cert pinning (the `f`
  field in the provisioning payload) is parsed but not yet enforced — **TODO**.

**`rs485/`** — the master side of the wire protocol. Frame codec with sync bytes
`0xAA 0x55`, 16-bit length, ADDR/SEQ/TYPE, CRC-16/CCITT-FALSE. A background poll
task issues `POLL` every ~20 ms, pulls queued Core events, dispatches them, and
ACKs them. A single bus mutex serialises transactions.

**`fw/`** — `fw_update` streams an HMI app image from SD into the inactive OTA
partition (Arduino Update), then reboots. `fw_core_update` pushes an RP2040
image to the Core over RS485 in 512-byte chunks with SHA-256 verification.

**`display/`**  — RGB LCD at 800×480, 16 MHz pixel clock,
two driver-managed framebuffers in PSRAM. To eliminate tearing, the driver
follows the Waveshare "avoid-tearing" pattern: LVGL renders into the inactive
framebuffer and the flush callback blocks on a vsync semaphore before swapping,
so the panel never scans a half-written frame. The RGB DMA runs on **PRO_CPU**;
all application work (LVGL, inv_sync) is pinned to **APP_CPU** at priority 1 —
any load on PRO_CPU causes visible tearing.

> An HMI graphics/tearing refinement was in progress alongside this
> documentation; the exact tearing-mode details in `display.cpp` may have
> shifted. The principle (vsync-gated double-buffer swap, app work off PRO_CPU)
> holds.

### UI screens (`ui/screens/`)

| Screen | Purpose |
|---|---|
| Home | 5 large action tiles: Load, View, Pick, Rack, Settings. |
| Load | Scan a reel QR, see part details, place into a lit empty slot. |
| View | Browse slots; Find (flash LED) and Pick per part. |
| Rack (dot grid) | Occupancy grid across all ports, colour-coded by state. |
| Pick (list) | Active pick jobs; partial jobs show Resume. |
| Pick (active) | The selected job's items with per-item progress. |
| Settings | Network, firmware update, self-test, slot/divider commissioning. |
| Settings → Network | WiFi + InvenTree URL/token, *Scan setup code* provisioning. |
| Settings → Self-test | Button/LED/reel diagnostics. |
| Settings → Firmware | HMI/Core versions, SD image picker, update. |
| Settings → Slots / Dividers | Commission module counts and divider layout. |

Fonts were deliberately enlarged for the 4.3" screen (the dot grid moved off
Home onto its own Rack screen; "Configure" was renamed "Settings").

### Threading model (summary)

| Task | CPU | Priority | Role |
|---|---|---|---|
| LVGL | APP | 2 | UI refresh, state mutation, event dispatch |
| inv_sync | APP | 1 | health poll, reconcile, op queue |
| rs485 poll | (app) | — | pull Core events every ~20 ms |
| state_store writer | — | — | periodic SD flush of dirty slots/jobs |

All InvenTree calls and RS485 transactions are blocking and run off the LVGL
task; results are posted back via a "dispatch on LVGL" helper.

## 3. RP2040 Core firmware (`core-fw/`)

C++ on PlatformIO (arduino-pico). The Core is the RS485 slave that drives the
reel modules. It is production firmware: `reel_id` = port (0–3), 1–4 chained
modules per port, 32 input bits per module, NeoPXL8 PIO-driven LEDs.

Responsibilities:

- **Serve the RS485 protocol** as a slave at address 0x01: respond to system,
  reel-I/O, LED, and firmware messages; answer the master's ~20 ms `POLL` with
  any queued events.
- **Sample inputs** at 100 Hz (10 ms), 2-sample debounce, and emit
  `INPUT_CHANGE` events when slot/divider bits change.
- **Sample sense** per port (~10 Hz/channel) and emit `REEL_INSERTED` /
  `REEL_REMOVED` when the module count changes.
- **Drive LEDs** via NeoPXL8 with a staging/commit pattern so multi-port updates
  show atomically (no tearing across strips).
- **Handle firmware updates**: stage a new image (Arduino-pico Updater), verify
  SHA-256, commit, and reboot; the OTA bootloader provides A/B rollback.
- **Queue events** in a 32-slot ring with sequence numbers; resend un-ACK'd
  events on each poll (because on a half-duplex bus the slave cannot transmit
  whenever it wants).

Key config (`core-fw/src/config.h`): `N_PORTS=4`, `MAX_MODULES_PER_PORT=4`,
`MODULE_LEDS=16`, `MODULE_INPUT_BITS=32`, `RS485_BAUD=115200`.

## 4. InvenTree plugin (`inventree-plugin/smart_reel/`)

Python plugin (version 0.2.0, slug `smartreel`). Layered:

```
core.py       plugin class: settings, URL routes, web panels
api.py        DRF views — thin HTTP layer, op_id idempotency, auth/error mapping
services.py   domain logic against InvenTree models (StockItem.move, metadata)
static/panel.js   the two web panels (Build Order + provisioning)
```

Mixins: `UrlsMixin` (custom routes under `/plugin/smartreel/`),
`SettingsMixin` (Staging/Pulled location settings + optional HMI URL),
`UserInterfaceMixin` (web panels). Barcode resolution goes through InvenTree's
barcode plugin registry. See [InvenTree Integration](05-inventree-integration.md)
for the full picture (rack identity, sync model, multi-rack).

## 5. Mock InvenTree (`debug-fw/mock-inventree/`)

A FastAPI service that implements the same `/api/v1/*` contract so the HMI can
be developed without a live InvenTree. Serves HTTPS on `:8443` (self-signed
cert under `certs/`), token `dev-token` by default, with the same `op_id`
idempotency (10-minute cache). It also serves a dashboard and a
`GET /_dev/provision` endpoint that prints the `SRPROV1:` payload + QR. It is
single-rack; multi-rack lives only in the real plugin. See
[InvenTree Integration §6](05-inventree-integration.md#6-the-mock-server).

## 6. Where the components agree on the contract

The HMI, the real plugin, and the mock all speak the identical
`/api/v1/*` contract. `docs/user-stories.md` is the behavioural source of
truth; `docs/hmi-plugin-api.md` plus
[API Reference](04-api-reference.md) document the wire shapes.
</content>

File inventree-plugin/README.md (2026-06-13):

# inventree-smart-reel

InvenTree plugin for the SmartReel smart reel holder.

Implements the HMI ↔ plugin contract from `docs/hmi-plugin-api.md` (repo
root) under `/plugin/smartreel/api/v1/…`, plus two web-UI panels:

- **Build Order page → "SmartReel" panel** — send the build's BOM to the
  rack as a pick job, watch per-item progress, remove/resend.
- **Rack location page → "SmartReel HMI" panel** — provisioning QR
  (`SRPROV1:` payload with URL + dedicated API token). Scan it from the
  HMI instead of typing credentials.

## Structure

```
smart_reel/
  core.py       # plugin class: settings, URL routes, UI panels
  api.py        # DRF views (thin HTTP layer, op_id idempotency)
  services.py   # domain logic against InvenTree models
  static/panel.js  # both web panels (no build step)
```

## Multiple racks

One instance drives many independent SmartReel units. Each rack is its
own StockLocation tagged `metadata['smartreel'] = {"is_rack": true}`;
provisioning binds the issued API token to that rack
(`token.metadata['smartreel_rack']`), so the HMI's token alone tells the
plugin which rack it's driving — no HMI/wire change. An unbound token is
refused (409). Provision each rack from its stock-location page → the
"SmartReel HMI" panel. `./test-multirack.sh` covers rack isolation.

## Behaviour notes

- **Slots** are StockLocation children of a rack location, carrying
  `metadata['smartreel'] = {'slot': n}`; created/grown by
  `POST /rack/register` (which targets the token's rack).
- **Picks are whole-reel** `StockItem.move()` transfers (audit-trailed) to
  the staging location — no quantity math.
- **Pick jobs** live in the source Build's `metadata['smartreel']`
  (with a target rack pk); job status is derived
  (`pending`/`partial`/`done`).
- **Anomalies** append to the rack location's
  `metadata['smartreel_anomalies']` (capped at 200).

## Settings (InvenTree → Settings → Plugins → Smart Reel)

| Setting | Meaning |
|---|---|
| Staging location | default destination for picked reels (per-rack override via metadata) |
| Pulled location | destination for anomaly-cleared reels (per-rack override via metadata) |

Racks are not a setting — provision each from its stock-location page.

InvenTree must have **plugin URL integration enabled**
(`ENABLE_PLUGINS_URL`) for the API to be reachable.

## Dev install

Installed (editable) into the local InvenTree docker instance at
`~/Desktop/Projects/inventree/` — see the README there for the
mount/reload workflow. Restart `inventree-server` + `inventree-worker`
after code changes. `./test-live.sh` exercises the full contract against
that instance.

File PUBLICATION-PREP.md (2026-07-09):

# Publication prep checklist

Working tracker for the pre-publication review pass (delete before final public push,
or keep as a record — your call). Generated 2026-06-25.

## Blockers (must fix before posting)
- [x] Add MIT LICENSE file at repo root (copyright holder = "Lukas Severinghaus" — change to Freefly Systems if that's the correct owner)
- [x] Credentials → env vars: `set-hmi-url.sh`, `test_live.py`, `test_multirack.py`
- [x] Internal network names → placeholders: `app_state.cpp`, `config_store.cpp`, `dev-restart.sh` (also location_id 42→0)
- [x] Fix stale broken `set-hmi-url.sh` `/provision` call (now takes optional rack-pk arg)

## Correctness bugs
- [x] `core-fw/src/main.cpp` — require successful `FW_VERIFY` before `FW_COMMIT` (new `s_fw_verified` gate)
- [x] `esp32-hmi/src/net/wifi_mgr.cpp` — WiFi event callback now marshals online state via `dispatch_on_lvgl`
- [x] `inventree-plugin/smart_reel/api.py` — `token.set_metadata(...)` moved inside `transaction.atomic()`
- [x] `inventree-plugin/smart_reel/services.py` — `enqueue_locate` now locks the rack row (`select_for_update`)

## Docs cleanup
- [x] Removed `docs/review-feedback.md`, `docs/review-feedback-solutions.md`, `docs/test-plan.md`
- [x] Fixed the `test-plan.md` reference in `docs/README.md`

## Unit tests
- [x] RS485 frame/protocol codec host tests (`tests/`, `make`) — 67 checks pass
- [x] Plugin `services.py` pytest suite (`inventree-plugin/test_services.py`) — 10 tests pass

## Done earlier
- [x] README AI disclaimer + security note added; Tests section added

## NOT done (out of scope for this pass — flagged for your call)
- [ ] TLS `setInsecure()` in `inv_api.cpp:92` — still disabled; now disclaimed in README + known-bugs. Implement cert pinning before untrusted-network deployment.
- [ ] Rename misleading `mock_*` state mutators in `app_state.cpp` (production code, not test scaffolding).
- [ ] 30+ `// review item N/R/B` code comments reference the now-removed `docs/review-feedback.md`; harmless but orphaned.
- [ ] `inv_api.h:5` header comment says "HTTP or HTTPS"; runtime is HTTPS-only.
- [ ] `core-fw` symlinked shared headers won't materialize on a default Windows `git clone` — worth a build note.
- [ ] Firmware was NOT recompiled here (no PlatformIO toolchain/hardware in this environment); edits are minimal/surgical — build before flashing.
- [ ] Confirm copyright holder in LICENSE / `pyproject.toml` author email before publishing.

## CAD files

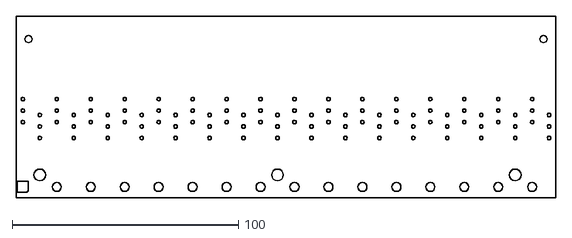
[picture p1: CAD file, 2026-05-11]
pcbs/ReelPCB/Smart Reel-PCB-Tiled-2026-05-07 15-32-16.dxf
238.5 x 80.0

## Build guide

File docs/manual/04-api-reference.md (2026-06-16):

# SmartReel — API Reference

Two interfaces are documented here:

- **Part A — the HMI ↔ plugin HTTP API** (`/api/v1/*` over HTTPS), implemented
  identically by the InvenTree plugin and the development mock.
- **Part B — the RS485 wire protocol** between the HMI and the Core firmware.

This builds on `docs/hmi-plugin-api.md` and `docs/smartreel-rs485-protocol.md`
and is reconciled against the code. Where the code differs from the older docs
it is flagged.

---

## Part A — HMI ↔ plugin HTTP API

### A.1 Base URL and routing

- Real plugin: `https://<inventree-host>/plugin/smartreel`
- Mock: `https://<dev-host>:8443`

The HMI appends `/api/v1/<path>` to its configured base URL, so both servers
are reached identically.

### A.2 Conventions

- **Auth** — every endpoint except `GET /health` requires
  `Authorization: Token <token>`. The real plugin accepts InvenTree API tokens;
  the mock compares against `SR_TOKEN` (default `dev-token`).
- **HTTPS only** — the HMI refuses to send the token over cleartext; non-HTTPS
  base URLs are rejected client-side.
- **Idempotency** — every mutating request carries an `op_id` string,
  `hmi-<chip-id>-<millis>-<n>`. The server caches `op_id → response` for
  **10 minutes** and replays the cached response on retry. The HMI's op queue
  retries until success precisely because this makes retries safe.
- **Slot numbers are physical positions** (1..N). Each maps to an InvenTree
  structural sub-location of the rack location, so a part shows as
  e.g. "SmartReel Rack A / Slot 32".
- **Rack identity rides on the token** — see [A.5](#a5-rack-identity--multi-rack).
- **Errors** — non-2xx with `{"detail": "<human-readable>"}`. Status mapping in
  the plugin: `404` not found, `409` conflict (slot occupied / logically empty /
  unbound token), `400` bad request, `403` not staff (provision).

### A.3 Endpoints

#### `GET /health` — liveness (no auth)
```jsonc
{ "ok": true, "server": "smartreel-plugin", "version": "0.2.0", "time": "..." }
```
Marked auth-exempt server-side. The HMI polls this to set its online/offline
state.

#### `POST /rack/register` — boot-time self-registration
```jsonc
// req
{ "n_slots": 64, "op_id": "..." }
// resp
{ "location_id": 42, "slot_locations": [ { "slot": 1, "location_id": 4201 }, ... ] }
```
Idempotent. Ensures the rack location and one sub-location per physical slot
("Slot 01"…"Slot NN", tagged `metadata['smartreel']={'slot':n}`); creates
missing ones if `n_slots` grew. Rack is resolved from the token.

#### `GET /rack` — full rack snapshot
Used at boot and for periodic reconciliation. Doubles as the reconcile source
(detecting stock moved in InvenTree without a physical removal).
```jsonc
{
  "location_id": 42,
  "n_slots": 64,
  "slots": [
    {
      "slot": 3,
      "location_id": 4203,
      "stock": {                  // null when logically empty
        "id": 1001,
        "qty": 5000,
        "batch": "B-241001",
        "barcode": "MOCK-PART-00001",
        "part": { "id": "R-10K-0805", "name": "RES 10kohm 1% 0805",
                  "pkg": "0805", "mfg": "Yageo" }
      }
    }, ...
  ],
  "pickjobs_available": 2
}
```

#### `GET /rack/occupancy` — cheap occupancy fingerprint
```jsonc
{ "rev": "9f2a1c0b4d7e6f81" }
```
An opaque hash over the rack's slot occupancy (+ pending locates). The HMI polls
this every ~5s and runs the full `GET /rack` reconcile only when `rev` changes,
so a reel moved out of a slot in InvenTree is detected within ~10s without a full
snapshot each poll (item 6). Compare for equality only; the value is not stable
across server versions.

#### `POST /barcode/resolve` — what did I just scan?
```jsonc
// req
{ "code": "<raw scanned string>", "op_id": "..." }
// resp
{
  "type": "stockitem" | "part" | "location" | "unknown",
  "stock": { ...same shape as rack snapshot stock, plus "slot_num": 3|0 ... },
  "part":  { ... },              // when type == "part"
  "message": "Unknown barcode"   // when type == "unknown"
}
```
The real plugin resolves through InvenTree's barcode plugin registry, so any QR
InvenTree can print (including StockItem labels) resolves. `stock.slot_num` is
non-zero when the item is already in a rack slot. Rack is optional here (only
used to fill `slot_num`).

#### `POST /rack/slots/{n}/assign` — load a reel into a slot
```jsonc
// req
{ "stock_item_id": 1001, "op_id": "..." }
// resp
{ "slot": 3, "stock": { ... } }
// errors: 404 unknown slot/stock, 409 slot occupied by a different item
```
Transfers the StockItem into the slot's sub-location (audit trail via
`StockItem.move()`). If the item was in another rack slot, that slot is
implicitly freed.

#### `POST /rack/slots/{n}/pick` — single pick (whole reel)
```jsonc
// req
{ "op_id": "...", "destination_id": null }   // destination optional
// resp
{ "slot": 3, "stock_id": 1001, "moved_to": 99 }
// errors: 404 unknown slot, 409 slot logically empty
```
**Whole-reel semantics**: the StockItem moves to `destination_id` if given,
else the configured **Staging** location, and the slot becomes logically empty.
No quantity math.

#### `POST /rack/slots/{n}/clear` — reconcile a manual removal
```jsonc
// req
{ "op_id": "...", "reason": "anomaly:removed" }
// resp
{ "slot": 3, "stock_id": 1001, "moved_to": 98 }
```
Moves the slot's stock to the configured **Pulled** location. Returns 2xx even
if the slot was already empty (idempotent goal state).

#### `GET /pickjobs` — list pick jobs
```jsonc
{
  "jobs": [
    {
      "id": "BO-0042",
      "name": "PCB-Rev-A x 5",
      "requested_at": "2026-06-11T14:02:00Z",
      "status": "pending" | "partial" | "done",
      "destination_id": 99,
      "items": [
        {
          "idx": 0,
          "part_id": "R-10K-0805",
          "part_name": "RES 10kohm 1% 0805",
          "qty": 250,                  // required qty, informational on the HMI
          "picked": false,
          "located_slots": [3, 17]     // rack slots currently holding this part
        }, ...
      ]
    }, ...
  ]
}
```
- One **item** = one part. Removing a reel of that part from any lit slot picks
  the item (one reel per item).
- `status` is **derived server-side**: `pending` / `partial` / `done`.
- Without query args, returns only the requesting token's rack's jobs (HMI use).
  With `?all=1` (session auth) returns every rack's jobs (web panel).
- Items whose part isn't in the rack have `located_slots: []`.

#### `POST /pickjobs/{id}/items/{idx}/pick` — pick one job item
```jsonc
// req
{ "slot_num": 3, "op_id": "..." }
// resp
{ "item": { ...updated item... }, "job_status": "partial" | "done" }
// errors: 404 job/item/slot, 409 slot doesn't hold the item's part / already picked
```
Validates the slot holds the item's part, performs a whole-reel pick to the
job's destination, marks the item picked.

#### `GET /pickjobs/options?build_id={id}` — candidate reels for a build
```jsonc
{
  "lines": [
    {
      "part": 12, "part_id": "R-10K-0805", "part_name": "RES 10kohm 1% 0805",
      "qty": 250,
      "candidates": [
        { "stock_id": 1001, "qty": 5000, "batch": "A",
          "rack_id": 7, "rack_name": "Rack A", "slot_num": 3 }, ...
      ]
    }, ...
  ]
}
```
Web-panel endpoint (session auth). For each BOM line, every in-stock reel of
that part that lives in **any** SmartReel rack — what the panel's reel picker
offers (item 10a).

#### `POST /pickjobs/from-build` — create jobs from a Build Order
```jsonc
// req
{ "build_id": 42, "stock_ids": [1001, 1002], "destination_id": null, "op_id": "..." }
// resp
{ "jobs": [ { ...job object (rack A)... }, { ...job object (rack B)... } ] }
```
Web-panel endpoint (session auth). The selected reels are grouped by the rack
that holds them, creating **one job per rack** (item 10b); each job item is
pinned to its `stock_id`, so only that reel's slot lights. Replaces any prior
SmartReel jobs on the build.

#### `DELETE /pickjobs/{id}` — remove a build's jobs
```jsonc
{ "deleted": "BO-0042" }
```
Clears every rack's job for the build.

#### `GET /racks` — list configured racks (web panel)
```jsonc
{ "racks": [ { "location_id": 7, "name": "SmartReel Rack A", "n_slots": 64 }, ... ] }
```

#### `GET /parts/locate?part_id=R-10K-0805` — find a part
```jsonc
{ "part_id": "R-10K-0805", "slots": [3, 17] }
```
Powers "find this part" independent of pick jobs, scoped to the token's rack.
`part_id` may be an IPN or a pk string.

> The locate capability was being refined alongside this documentation (a
> possible "locate mixin" on the plugin). The `GET /parts/locate` query above is
> the current implementation; the area may evolve.

#### `POST /anomaly` — report sensor-detected anomalies
```jsonc
// req
{ "kind": "removed" | "added" | "divider", "slot_num": 12,
  "detail": "free text", "op_id": "..." }
// resp
{ "id": 7, "logged": true }
```
Audit log on the rack location's metadata (capped at 200 entries). Inventory
correction is separate (`/clear`).

#### `GET /provision?location=<pk>[&rotate=1]` — provision a rack (staff only)
Session-authenticated, staff only. Tags the location as a rack, mints/rotates an
API token bound to it, and returns the setup payload + QR:
```jsonc
{ "payload": "SRPROV1:{...}", "svg": "<svg>...", "token_name": "smartreel-rack-7",
  "base_url": "https://inventree.example/plugin/smartreel", "rack": { ... } }
```

### A.4 Provisioning payload (`SRPROV1:`)

Delivered as a QR so credentials don't have to be typed on the HMI:
```jsonc
SRPROV1:{"u":"https://inventree.example/plugin/smartreel",
         "t":"inv-token-...",
         "f":"AB:CD:..."}   // optional TLS cert SHA-256 fingerprint
```
- `SRPROV1:` prefix versions the payload and distinguishes it from a part
  barcode.
- `u` — plugin base URL (HMI appends `/api/v1/...`).
- `t` — InvenTree API token (or `dev-token` from the mock).
- `f` — optional cert fingerprint for pinning. **Parsed by the HMI but not yet
  enforced** (cert pinning is TODO; the HMI currently does not verify the TLS
  cert).

On the HMI: Settings → Network → *Scan setup code* → scan the screen. The HMI
stores URL + token and immediately runs `GET /health`.

### A.5 Rack identity & multi-rack

- Every rack is its own InvenTree `StockLocation` tagged
  `metadata['smartreel'] = {"is_rack": true, "staging"?, "pulled"?}`. Slots are
  child locations tagged `{"slot": n}`.
- **The token carries the rack.** Provisioning binds the issued API token to the
  location via `token.set_metadata('smartreel_rack', <loc_pk>)`. Every
  rack-scoped request resolves its rack from `request.auth`. An **unbound token
  is refused with 409** — re-provision. There is **no global rack setting** and
  no shared-rack fallback; every unit, including the first, is provisioned from
  its location page.
- `/health` and `/barcode/resolve` are rack-independent (resolve only uses the
  rack to fill `slot_num`).
- Pick jobs store a target rack pk; `GET /pickjobs` and `located_slots` are
  scoped to the requesting token's rack. `POST /pickjobs/from-build` takes
  `stock_ids` and fans out one job per rack. `GET /pickjobs?all=1` and `GET /racks` are for
  the web panel.

### A.6 Differences from `docs/hmi-plugin-api.md`

The code matches that contract closely. Notable points confirmed in code:

- Multi-rack is fully implemented (v0.2.0); the global `RACK_LOCATION` setting is
  gone — only `STAGING_LOCATION` and `PULLED_LOCATION` (instance-wide defaults,
  per-rack overridable in metadata) plus an optional HMI-URL setting remain.
- The op_id cache TTL is **600 s (10 minutes)**, matching the doc's "≥10
  minutes".
- The plugin issues the provisioning token for the staff user performing the
  provisioning (named `smartreel-rack-<pk>`); there is no separate fixed
  `smartreel-hmi` machine user baked into the plugin code.

---

## Part B — RS485 wire protocol

Between the HMI (bus master, address `0xFF`) and the Core (slave, `0x01`).
Constants below are from `esp32-hmi/src/rs485/rs485_proto.h` and
`core-fw/src/config.h`; both ends share the same frame codec.

### B.1 Frame format

```
+------+------+------+------+------+------+------+--------------+------+------+
| 0xAA | 0x55 | LEN_H| LEN_L| ADDR | SEQ  | TYPE | PAYLOAD ...  | CRC_H| CRC_L|
+------+------+------+------+------+------+------+--------------+------+------+
```

- **Sync** `0xAA 0x55` — receiver hunts for these to resync after a glitch.
- **LEN** — big-endian 16-bit; counts ADDR through end of PAYLOAD (minimum 3).
- **ADDR** — `0x00` broadcast, `0x01` Core, `0xFF` master (ESP32).
- **SEQ** — request/response matching; a response echoes the request's SEQ.
- **TYPE** — bit 7 set = response (`0x10` request → `0x90` response); bit 6 set
  = error response (`0xD0`). Low 6 bits are the command code.
- **CRC** — CRC-16/CCITT-FALSE (poly `0x1021`, init `0xFFFF`, no reflect, no
  final XOR) over ADDR..end-of-PAYLOAD.
- **MAX_PAYLOAD** = 768 bytes; max frame 777 bytes.
- **Baud** = 115200, half-duplex.

### B.2 Message catalog (request codes)

#### System (0x0_)
| Code | Name | Dir | Notes |
|---|---|---|---|
| 0x00 | PING | E→C | echo |
| 0x01 | GET_VERSION | E→C | → major, minor, patch, build_id(4B), hw_rev |
| 0x02 | GET_STATUS | E→C | → uptime_s(4B), reels_present bitmap, error_flags(2B) |
| 0x03 | RESET | E→C | reason byte (0=normal, 1=enter_update_mode) |
| 0x04 | POLL | E→C | → "no events" or queued events (see B.4) |
| 0x05 | ACK_EVENTS | E→C | count + seq bytes; clears ACK'd events |

#### Reel I/O (0x1_)
| Code | Name | Dir | Notes |
|---|---|---|---|
| 0x10 | GET_REEL_INFO | E→C | reel_id (or 0xFF all) → per-port present, sense_mv, module_count |
| 0x11 | READ_INPUTS | E→C | reel_id → module_count + 4B input word per module |
| 0x12 | SET_POLL_RATE | E→C | reel_id, rate_hz(2B) |

`reel_id` is the **port** number (0–3). Each module's 32-bit input word is laid
out `D0 S0 D1 S1 … D15 S15` (D = divider, S = slot-present).

#### LED control (0x2_)
| Code | Name | Dir | Notes |
|---|---|---|---|
| 0x20 | SET_REEL_PIXELS | E→C | reel_id, start_idx, count, RGB… (stages to back buffer) |
| 0x21 | FILL_REEL | E→C | reel_id, R, G, B (stages + commits) |
| 0x22 | SET_BRIGHTNESS | E→C | reel_id (or 0xFF), brightness 0–255 |
| 0x23 | SET_ANIMATION | E→C | reel_id, anim_id, params (runs on the Core) |
| 0x24 | COMMIT | E→C | reel_bitmap — atomic `show()` across selected ports |

The stage-then-COMMIT pattern avoids visible tearing when updating multiple
ports in one frame.

#### Firmware update (0x3_)
| Code | Name | Dir | Notes |
|---|---|---|---|
| 0x30 | FW_BEGIN | E→C | total_size(4B), SHA-256(32B), version(4B) |
| 0x31 | FW_CHUNK | E→C | offset(4B) + data (512B); → bytes_received(4B) |
| 0x32 | FW_VERIFY | E→C | Core re-hashes the image; OK or hash-mismatch |
| 0x33 | FW_COMMIT | E→C | commit + self-reset |
| 0x34 | FW_CONFIRM | E→C | clears the "needs confirm" flag after a good boot |
| 0x35 | FW_BOOTED | C→E | event: new image booted |

> **Discrepancy with `docs/smartreel-rs485-protocol.md`.** That note places
> firmware messages in category `0xF_`. The **code uses `0x30`–`0x35`** because
> a `0xF_` code would have both the response (bit 7) and error (bit 6) bits set,
> making firmware requests indistinguishable from error responses on the wire.
> Trust the code: firmware messages are at `0x30`–`0x35`.

#### Async events (0x8_, Core → HMI, delivered in the POLL response)
| Code | Name | Payload |
|---|---|---|
| 0x80 | INPUT_CHANGE | port, module, prev(4B), now(4B), ts_ms(4B) |
| 0x81 | REEL_INSERTED | port, module_count, sense_mv(2B) |
| 0x82 | REEL_REMOVED | port, module_count |
| 0x83 | SENSE_THRESHOLD | port, sense_mv, threshold_id |
| 0x8F | LOG | level, ASCII message |

#### Error codes (first payload byte of an error response)
| Code | Meaning |
|---|---|
| 0x00 | OK |
| 0x01 | unknown command |
| 0x02 | bad payload |
| 0x03 | reel absent |
| 0x04 | busy (e.g. flash erasing) |
| 0x10 | FW hash mismatch |
| 0x11 | FW offset out of range |
| 0x12 | FW wrong state |

### B.3 Polling and half-duplex events

On a half-duplex bus the Core cannot transmit unsolicited. The master issues
`POLL` (0x04) every ~20 ms; the Core answers with up to N queued events. The
Core keeps a **32-slot event ring** with per-event sequence numbers and resends
un-ACK'd events on each poll until the master `ACK_EVENTS` (0x05) clears them.
This keeps button-event latency under ~50 ms while guaranteeing delivery up to
the ring's capacity.

POLL response payload: `count`, then for each event `type, seq, len, data…`.

### B.4 Core firmware update flow

| Step | Message | Notes |
|---|---|---|
| 1 | FW_BEGIN | size + SHA-256 + version; Core stages (erase can take seconds → BUSY) |
| 2 | FW_CHUNK ×N | 512-byte chunks; Core ACKs bytes received; master retries gaps |
| 3 | FW_VERIFY | Core re-hashes, compares to the announced SHA-256 |
| 4 | FW_COMMIT | Core writes metadata (pending slot, needs-confirm) and resets |
| 5 | (bootloader) | A/B bootloader boots the new slot |
| 6 | FW_BOOTED → FW_CONFIRM | new app announces itself; master confirms to lock it in |

If the new firmware never sends `FW_BOOTED`/never gets `FW_CONFIRM`, the
bootloader rolls back to the previous slot on the next reset.
</content>

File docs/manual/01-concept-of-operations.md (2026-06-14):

# SmartReel — Concept of Operations

## 1. What SmartReel is

SmartReel is a smart storage rack for reels of surface-mount electronic
components, designed to work hand-in-hand with InvenTree, an open-source
inventory management system. A physical SmartReel rack is made of one or more
**reel modules**, each providing a row of slots. Every slot:

- senses whether a reel is physically present (a button under the reel),
- has an addressable RGB LED to guide the operator, and
- can be widened by pulling **dividers** between slots to fit larger reels.

A touchscreen **HMI** (Human–Machine Interface) mounted on the rack is the
operator's control panel. The HMI talks to the rack hardware over an RS485
serial link and to InvenTree over HTTPS. InvenTree stays the single source of
truth for inventory; SmartReel records *where* each reel physically lives
("SmartReel Rack A, Slot 32") and guides the operator to the right slot.

The goal is to remove the two annoying parts of bench-stock management:
remembering where a reel is, and keeping the digital inventory in step with the
physical one. The operator scans, the rack lights up, and the inventory updates
itself.

## 2. Who uses it

- **Shop-floor operator / technician** — the everyday user. Stores received
  reels, picks single reels, and works through pick jobs for builds. Interacts
  almost entirely through the HMI touchscreen and a QR scanner. The
  [Operator User Manual](06-operator-manual.md) is written for this person.
- **Inventory / production manager** — works in InvenTree's web UI. Receives
  stock, creates build orders, and sends pick jobs to a rack from the Build
  Order page. Provisions new racks from the InvenTree location page.
- **Installer / maintainer** — sets up a rack: wires it, commissions the slot
  layout on the HMI, provisions it against InvenTree, and performs firmware
  updates.

The target environment is a small-to-medium business or a serious hobbyist
doing PCB assembly, who already runs InvenTree and wants to automate the
monotonous parts of inventory handling.

## 3. The pieces, at a glance

```
   Operator                InvenTree manager
      |                            |
   [touchscreen]              [web browser]
      |                            |
  +-------+   RS485   +--------+   HTTPS   +-----------------------+
  |  HMI  |<--------->| Core   |           |     InvenTree         |
  | ESP32 |           | PCB    |           |  + SmartReel plugin   |
  |  -S3  |           | RP2040 |           +-----------------------+
  +-------+           +--------+
      |                  |
      | HTTPS            | drives reel modules (LEDs + sensors)
      v                  v
  InvenTree         [Reel modules: slots, dividers, LEDs]
```

See the [Software Architecture](03-software-architecture.md) and
[Hardware](02-hardware.md) docs for the full breakdown.

## 4. End-to-end workflows

The behavioural source of truth is `docs/user-stories.md`. The workflows below
describe what actually happens across the HMI, the rack hardware, and InvenTree.

### 4.1 Commissioning a rack

Done once when a rack is installed, and again whenever its physical layout
changes.

1. **Wire and power the rack.** Reel modules chain off the Core PCB's ports;
   the HMI connects to the Core over RS485. (See [Hardware](02-hardware.md).)
2. **Provision against InvenTree.** In InvenTree, open the stock location that
   represents this rack, open the **SmartReel HMI** panel, and click
   *Provision*. The plugin tags that location as a rack, mints a dedicated API
   token bound to it, and shows a **setup QR code** (`SRPROV1:` payload with
   the plugin URL + token).
3. **Scan the setup code on the HMI.** Settings → Network → *Scan setup code*.
   The HMI stores the URL and token and immediately runs a health check. From
   now on the rack's identity rides on its token — no rack number to configure.
4. **Commission the slot layout.** On first power-up the HMI follows the live
   hardware topology it reads from the Core (how many modules are on each port,
   where the dividers are). The installer reviews this in
   Settings → Slots / Dividers and **commits** it. After commit, the HMI
   validates the live hardware against the committed layout and flags any
   deviation as an anomaly.
5. **Register slots with InvenTree.** On first successful contact the HMI calls
   `POST /rack/register`, which creates one InvenTree sub-location per physical
   slot ("Slot 01" … "Slot NN") under the rack location.

> Multiple racks: one InvenTree instance can drive many racks. Each is
> provisioned separately and identified by its own token. There is no global
> "rack number" setting.

### 4.2 Stocking reels (put-away / load)

When new reels arrive, the operator first receives them into InvenTree
normally (so each reel becomes a StockItem with a QR label). Then they store
them physically:

1. Operator walks to the HMI, taps **Load**, and scans the reel's QR code.
2. The HMI sends the scanned code to `POST /barcode/resolve`. InvenTree
   resolves it to the StockItem and returns the part name and quantity. If the
   reel is already recorded in a slot, the HMI says "already in slot N".
3. The HMI shows the part details and lights every **empty** slot as a
   candidate location.
4. The operator drops the reel into any lit slot. The slot's presence sensor
   fires; after a short debounce the HMI registers that slot as the reel's
   home and queues `POST /rack/slots/{n}/assign`. InvenTree moves the StockItem
   into that slot's sub-location (with an audit trail).
5. The slot LED returns to normal; the load is complete.

If the rack is offline, loads against the on-SD offline catalog stay local and
are reconciled later. Operations that change inventory are queued and retried.

### 4.3 Picking a single reel

For grabbing one whole reel.

1. Operator taps **View**, scrolls to the part (or uses *Find*, which flashes
   the slot LEDs for a few seconds), and taps **Pick**.
2. The HMI lights that slot. The operator can tap **Cancel** any time before
   removing the reel.
3. The operator lifts the reel out. The presence sensor releases; the HMI
   queues a **whole-reel pick** (`POST /rack/slots/{n}/pick`). InvenTree
   transfers the entire StockItem to the configured **Staging** location (or a
   per-pick destination). No quantity math — the whole reel left the rack.
4. The LED turns off; the slot is now logically empty.

Picking is **disabled while the rack is offline** (a banner explains why) to
keep SmartReel from drifting out of sync with InvenTree.

### 4.4 Job picking (kitting a build)

For assembling all the parts a build order needs.

1. In InvenTree, the manager opens a Build Order, opens the **SmartReel**
   panel, picks the target rack, and clicks *Send to SmartReel*. The plugin
   turns the build's BOM into a **pick job** (one item per part) stored on the
   build, scoped to that rack.
2. On the HMI, the operator opens **Pick**, selects the job, and the rack
   lights every slot that holds a part the job still needs.
3. For each item, the operator removes a reel from any lit slot (or taps the
   on-screen *Picked* button). The HMI reports `pickjobs/{id}/items/{idx}/pick`;
   InvenTree marks that item picked and moves the reel to the job's destination.
4. When all items are picked the job is **done** and disappears from the list.
5. **Partial picks resume.** If the operator cancels partway, already-picked
   items stay picked server-side; the job shows as *partially picked* with a
   **Resume** button and can be finished later. Cancel is local-only.

Items whose part isn't currently in the rack are shown as unfulfillable rather
than hidden.

### 4.5 Inventory reconcile (background)

InvenTree is the source of truth, and stock can move there without anyone
touching the rack (e.g. someone transfers a reel's StockItem in the web UI).
SmartReel detects and resolves these drifts:

- Every ~60 seconds (and on demand) the HMI fetches a full rack snapshot
  (`GET /rack`) and compares it to the physical truth from the sensors.
- **Moved in InvenTree but still physically present** → the HMI lights the slot
  amber and shows a "Stock moved in InvenTree" prompt instructing removal.
  Removing the reel resolves it (no inventory action — InvenTree already moved
  it).
- **Logically present but physically absent** (a reel yanked without a pick) →
  the HMI logs an anomaly and clears the slot to the **Pulled** location so the
  stock isn't lost.
- **Both present** → the HMI adopts InvenTree's part/quantity for that slot
  (boot-time sync).

Reconcile is skipped for slots the operator is actively working (a lit pick
target, a just-picked slot) and when the Core hardware mirror is invalid.

### 4.6 Firmware update

Two independent update paths exist (see the [API Reference](04-api-reference.md)
for the wire/partition detail):

- **HMI self-update** — the ESP32-S3 flashes a new application image from a
  file on its SD card into the inactive OTA partition, then reboots into it.
- **Core update over RS485** — the HMI streams a new RP2040 image to the Core in
  512-byte chunks (`FW_BEGIN` → `FW_CHUNK` × N → `FW_VERIFY` → `FW_COMMIT`),
  SHA-256 verified, with an A/B-slot bootloader that rolls back automatically
  if the new image fails to confirm after boot.

## 5. Online / offline philosophy

The HMI continuously health-checks InvenTree (every 15 s while up, every 5 s
while down) and shows an online/offline indicator. The guiding rule:

- **Reads and put-away** degrade gracefully offline (the HMI can show the SD
  offline catalog, and assigns queue for later).
- **Picks are blocked offline** to guarantee the rack never reports a removal
  that InvenTree doesn't know about.
- Every inventory-changing action is queued with an idempotency key (`op_id`)
  and retried until it succeeds, so a flaky network can't lose or double-apply
  a move.
</content>

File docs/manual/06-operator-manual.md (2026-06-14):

# SmartReel — Operator User Manual

A plain-language guide to using the SmartReel touchscreen for everyday work. No
technical background needed. If you're setting up a rack for the first time, see
the [Concept of Operations, Commissioning](01-concept-of-operations.md#41-commissioning-a-rack)
first.

## What SmartReel does for you

SmartReel is a storage rack for component reels with a touchscreen on it. It
remembers which reel is in which slot, lights up the right slot to guide you,
and keeps your InvenTree inventory up to date automatically. You mostly just
**scan, look for the lit slot, and place or pick the reel.**

## The Home screen

The Home screen has five big buttons:

| Button | Use it to… |
|---|---|
| **Load** | Put a new reel into the rack. |
| **View** | Browse what's in the rack, find a part, or pick one reel. |
| **Pick** | Work through a pick job for a build. |
| **Rack** | See the whole rack at a glance (a colour-coded grid of slots). |
| **Settings** | Network setup, firmware updates, diagnostics, slot setup. |

### The online indicator

There's an online/offline indicator on the status bar. When it shows
**online**, everything works. When it shows **offline**, the rack has lost its
connection to InvenTree — see [If the rack is offline](#if-the-rack-is-offline).

### What the slot lights mean

| Light | Meaning |
|---|---|
| Off | Normal occupied or empty slot. |
| Blue | This is your target — place a reel here, or pick from here. |
| Green | Just picked / completed. |
| Amber | Attention: a reel needs to be removed (it was moved in InvenTree). |
| Red | Error with this slot. |

When a slot has been widened by pulling dividers, **all** the LEDs in that wide
slot light up together.

---

## Task: Load a new reel (put-away)

Do this after a reel has been received into InvenTree.

1. Tap **Load** on the Home screen.
2. **Scan the reel's QR code** with the scanner. (No scanner? Tap to enter the
   code by hand.)
3. The screen shows the **part name and quantity**.
   - If it says **"already in slot N"**, that reel is already stored — you're
     done.
4. The rack lights up **every empty slot** in blue. These are your choices.
5. **Drop the reel into any lit slot.** The light turns off and the reel is now
   stored. SmartReel records its location in InvenTree for you.

To back out before placing the reel, tap **Cancel**.

---

## Task: Find a part

1. Tap **View**.
2. Scroll to the part (or search).
3. Tap **Find** next to it. The reel's slot flashes for a few seconds so you can
   spot it.

---

## Task: Pick one reel

1. Tap **View** and find the part.
2. Tap **Pick**. The reel's slot lights blue.
3. **Lift the reel out.** The light turns off and SmartReel records the removal
   in InvenTree (the reel moves to the Staging location).

To stop before removing the reel, tap **Cancel** — nothing changes.

> Picking only works while the rack is **online**. If it's offline, the Pick
> button is disabled and a banner explains why.

---

## Task: Work a pick job (kitting a build)

A pick job is a list of parts someone sent to this rack from a Build Order in
InvenTree.

1. Tap **Pick**. You'll see the available jobs.
   - A job marked **partially picked** has a **Resume** button — you can finish
     it later.
2. Tap a job to open it. The rack lights up **every slot** that holds a part the
   job still needs.
3. For each part:
   - **Lift a reel** from any lit slot for that part, **or**
   - tap the **Picked** button next to the item.
   That item is checked off.
4. When everything is checked off, the job is **done** and disappears.

If you tap **Cancel** partway through, the items you already picked stay picked.
The job shows as *partially picked* and you can come back and Resume it.

Parts that aren't in this rack show up as **unfulfillable** so you know to get
them elsewhere.

---

## Task: See the whole rack

Tap **Rack** for a colour-coded grid of every slot — handy for a quick overview
of what's occupied, empty, or needs attention.

---

## Handling problems

### A slot is lit amber and the screen says "Stock moved in InvenTree"

Someone moved that reel's record in InvenTree without taking the reel out of the
rack. **Remove the reel from the amber slot.** The light clears and everything
is back in sync. (You don't need to scan anything — InvenTree already knows.)

### I pulled a reel without picking it

SmartReel notices a reel that left without a pick, logs it, and moves that stock
to the **Pulled** location in InvenTree so it isn't lost. If you didn't mean to,
re-load the reel with the **Load** flow.

### A slot is red

There's a problem with that slot or its sensor. Try reseating the reel; if it
persists, tell your maintainer and run **Settings → Self-test**.

### If the rack is offline

The online indicator shows **offline** when the rack can't reach InvenTree.
While offline:

- **You can still load reels** (the change is saved and sent automatically once
  the connection comes back).
- **You cannot pick** — this is on purpose, so the inventory never gets out of
  step. The Pick button is disabled.
- SmartReel keeps trying to reconnect on its own. Once it's back online, any
  pending changes are sent automatically.

If it stays offline, check the WiFi/network and the InvenTree connection in
**Settings → Network**.

### Re-connecting / re-provisioning the rack

If credentials need refreshing (e.g. the token was rotated in InvenTree):

1. In InvenTree, open this rack's location page → **SmartReel HMI** panel →
   get the setup QR (rotate the token if needed).
2. On the HMI: **Settings → Network → Scan setup code**, and scan the screen.
   The rack tests the connection right away.

---

## Tips

- **Scan first, then place.** The lit slots only appear after a successful scan.
- **Any lit slot works** for loading — pick whichever is convenient.
- **The reel's presence button is what counts.** SmartReel reacts when you
  physically place or remove a reel, not just when you tap the screen.
- **Wide slots** (dividers pulled) hold larger reels; the whole group lights up
  as one.
- **Cancel is always safe** before you move a reel — it changes nothing.
</content>

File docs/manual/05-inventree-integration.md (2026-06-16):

# SmartReel — InvenTree Integration

How the SmartReel plugin lives inside InvenTree, how to install and configure
it, and the sync model the HMI uses to stay consistent with InvenTree.

## 1. How the plugin works

The plugin (`inventree-plugin/smart_reel/`, slug `smartreel`, v0.2.0) is a
standard InvenTree plugin that exposes a **workflow-shaped HTTP API** the HMI
calls, plus two web-UI panels. It deliberately does **not** proxy InvenTree's
generic REST API; instead it offers exactly the operations the HMI needs
(resolve / register / assign / pick / clear / pickjobs / locate / anomaly /
provision) and translates them into InvenTree model operations. That keeps the
HMI simple.

Layered source:

```
core.py     plugin class — settings, URL routes, UI panels
api.py      DRF views — HTTP layer, op_id idempotency, auth + error mapping
services.py domain logic — StockItem.move(), location/metadata management
static/panel.js  the two browser panels (no build step)
```

Mixins used: `UrlsMixin`, `SettingsMixin`, `UserInterfaceMixin`. Barcode
resolution rides on InvenTree's own barcode plugin registry, so any code
InvenTree can resolve (StockItem QR labels, linked custom codes) resolves here.

### Data model mapping

| SmartReel concept | InvenTree representation |
|---|---|
| A rack | a `StockLocation` tagged `metadata['smartreel']={"is_rack":true, ...}` |
| A slot | a child `StockLocation` of the rack, tagged `{"slot": n}`, named "Slot NN" |
| A reel in a slot | a `StockItem` whose `location` is that slot sub-location |
| A pick job | data stored on a `Build`'s `metadata['smartreel']` |
| An anomaly | an entry in the rack location's `metadata['smartreel_anomalies']` (cap 200) |

All stock movement uses `StockItem.move(destination, reason, user)`, which
creates a `StockHistory` audit entry. **Picks are whole-reel transfers** — the
entire StockItem moves; there is no quantity decrement model.

## 2. Installation and configuration

> Plugin installation follows InvenTree's normal plugin process; confirm
> specifics against the InvenTree version you run.

1. **Install the plugin** into the InvenTree instance (the package's entry point
   is `SmartReelPlugin = "smart_reel.core:SmartReelPlugin"`). Enable it in
   InvenTree's plugin settings.
2. **Enable plugin URLs and the plugin interface** in InvenTree's global
   settings (`ENABLE_PLUGINS_URL`, `ENABLE_PLUGINS_INTERFACE`) so the
   `/plugin/smartreel/...` routes and the web panels are served. Re-run
   InvenTree's frontend asset build (`invoke static`) if panel JS is stale.
3. **Configure plugin settings** (InvenTree → Settings → Plugins → Smart Reel):

   | Setting | Meaning |
   |---|---|
   | Staging location | default destination for picked reels (`STAGING_LOCATION`) |
   | Pulled location | destination for anomaly `/clear` removals (`PULLED_LOCATION`) |
   | HMI URL (optional) | explicit public base URL embedded in provisioning QRs; otherwise InvenTree's base URL or the request host is used |

   There is **no global rack-location setting** — racks are provisioned
   individually (next step). Staging/Pulled are instance-wide defaults that a
   rack can override in its own metadata.

4. **Provision each rack.** Open the `StockLocation` that represents the rack →
   the **SmartReel HMI** panel → *Provision*. The plugin tags the location as a
   rack, mints an API token bound to it, and shows the setup QR. Scan it on the
   HMI (Settings → Network → *Scan setup code*). Use *Rotate token* to revoke
   and reissue.

### Dev workflow (for plugin developers)

The plugin ships dev helpers (under `inventree-plugin/`):

- `dev-restart.sh` — restart the docker containers + health check.
- `test-live.sh` / `test_live.py` — ~32 contract checks against a running docker
  instance.
- `test-multirack.sh` / `test_multirack.py` — multi-rack isolation tests.
- `set-hmi-url.sh` — set the HMI-URL setting.

> The docker InvenTree dev instance serves plain HTTP via Caddy on
> `inventree.localhost`. The HMI is **HTTPS-only**, so for HMI↔real-InvenTree
> testing either enable HTTPS in the Caddyfile (with a LAN-IP SAN) or test
> against the mock (already TLS).

## 3. The sync model: op queue + reconcile

The HMI's `app/inv_sync` module owns *all* InvenTree traffic and keeps the rack
consistent through two mechanisms.

### 3.1 The op queue (writes)

Every inventory-changing action becomes an **op** on a 16-deep queue:
`Assign`, `Pick`, `JobPick`, `Clear`, `Anomaly`. Each op carries a unique
`op_id` and is retried (up to 20 attempts) until it succeeds:

- A network/5xx failure → retry.
- A `4xx` → permanent reject (logged); the next reconcile catches any resulting
  drift.

Because the server caches `op_id → response` for 10 minutes and replays it,
retries are safe and can never double-apply a move. This is what lets the HMI
keep working through a flaky link without losing or duplicating inventory
changes.

### 3.2 Reconcile (reads)

The HMI fetches a full snapshot (`GET /rack`) at boot, every ~60 s, and on
demand, then compares **server truth** (the snapshot) against **physical truth**
(the sensors via the Core's hardware mirror):

| Server | Physical | HMI action |
|---|---|---|
| empty (was occupied) | present | light slot amber + "Stock moved in InvenTree" prompt; removing the reel resolves it (no inventory call) |
| occupied | absent | log anomaly + `clear` the slot to the Pulled location |
| occupied | present | adopt the server's part/qty for that slot (boot sync) |

Reconcile skips slots the operator is actively working (a lit pick TARGET, a
just-PICKED slot) and skips entirely when the Core hardware mirror is invalid
(Core absent).

## 4. Online / offline behaviour

- The HMI health-checks the server every **15 s** while online and **5 s** while
  offline; "online" means the last good health check is younger than **45 s**.
- **Picks are blocked offline** (a banner explains why), so the rack can never
  report a removal InvenTree doesn't know about.
- **Put-away** degrades gracefully: assigns queue for later; loads against the
  on-SD offline catalog stay local until reconciled.
- The HMI is **HTTPS-only**; it refuses to send the token over cleartext.

## 5. Multi-rack support

One InvenTree instance can drive many independent racks. The design is
token-bound rack identity:

- Each rack is its own `StockLocation`; provisioning binds the issued API token
  to it (`token.metadata['smartreel_rack'] = <loc_pk>`).
- Every rack-scoped request resolves its rack from `request.auth`. An **unbound
  token is refused with 409** (re-provision).
- HMIs need no rack number and no wire/protocol change — the token alone tells
  the plugin which rack it is driving.
- Pick jobs are created from selected reels: the Build Order panel lists the
  candidate reels (`GET /pickjobs/options`), and `POST /pickjobs/from-build`
  takes `stock_ids` and fans out **one job per rack** that holds a selected reel.
  Each item is pinned to its `stock_id`. `GET /pickjobs?all=1` and `GET /racks`
  serve the web panel across all racks.

## 6. The mock server

`debug-fw/mock-inventree/` is a FastAPI service implementing the same `/api/v1/*`
contract so the HMI can be developed without a live InvenTree.

- Start: `./setup.sh` (one-off: venv + deps + cert), then `./run.sh` →
  `https://0.0.0.0:8443`, token `dev-token`. `SR_HTTPS=0 ./run.sh` for plain
  HTTP.
- Self-signed cert under `certs/` (generated by `gen-cert.sh`, with LAN-IP SANs
  and a printed SHA-256 fingerprint for HMI pinning).
- Same `op_id` idempotency (cache TTL `SR_OP_CACHE_TTL_S`, default 600 s).
- Provisioning: `GET /_dev/provision` returns the `SRPROV1:` payload + a QR SVG
  (via `segno`). The dashboard renders the QR so bench provisioning works the
  same way as the real plugin's panel.
- A dashboard (polls every 2 s) shows the rack grid, jobs, anomalies, and op
  cache. Dev helpers: `/_dev/reset`, `/_dev/anomalies`, `/_dev/ops`,
  `/_dev/inject_error` (to test failure UI).
- `smoke-test.sh` exercises the whole contract on a throwaway port.
- **Single-rack only** — multi-rack lives in the real plugin. The mock uses a
  fixed rack location id (`SR_RACK_LOCATION_ID`, default 42).

Key env vars: `SR_TOKEN`, `SR_HTTPS`, `SR_PORT`, `SR_HOST`,
`SR_RACK_LOCATION_ID`, `SR_STAGING_LOCATION_ID`, `SR_PULLED_LOCATION_ID`,
`SR_N_CHAINS`, `SR_SLOTS_PER_CHAIN`, `SR_LATENCY_MS`, `SR_OP_CACHE_TTL_S`.

## 7. Find / locate

`GET /parts/locate?part_id=<ipn-or-pk>` returns the slot numbers in the token's
rack currently holding the part — this powers the HMI's *Find* button
independent of pick jobs.

> A plugin "locate" feature was being refined alongside this documentation. The
> `/parts/locate` query is the current shape; if a dedicated locate mixin lands,
> the find flow may gain richer behaviour (e.g. driving the rack LEDs from the
> InvenTree side). Treat this section as current-state, possibly evolving.
</content>

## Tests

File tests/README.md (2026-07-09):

# Tests

Lightweight, host-runnable tests for the parts of SmartReel that can be checked
without hardware or a live InvenTree. They are deliberately dependency-free so
they run anywhere (and in CI) with just a C++ compiler and Python.

This is **not** full coverage — the firmware UI/RS485 transport and the plugin's
model-touching code are validated on real hardware and against a running
InvenTree (`inventree-plugin/test_live.py`, `test_multirack.py`). These suites
cover the shared, pure logic that is easy to break and expensive to debug on the
bench.

## RS485 frame codec (C++)

The frame encoder/decoder + CRC in `esp32-hmi/src/rs485/` is the wire format
spoken by *both* firmwares, so a regression breaks the whole bus. It is plain,
platform-independent C++ and compiles on the host:

```bash
cd tests
make            # builds and runs; exit code 0 on success
```

Requires any C++17 compiler (`g++`/`clang++`). No PlatformIO toolchain needed.

## Plugin services (Python)

Pure logic in `inventree-plugin/smart_reel/services.py` — op_id idempotency,
wire-id mapping, pick-job status — tested with stubbed Django symbols so no
InvenTree install is required:

```bash
cd inventree-plugin
python3 test_services.py        # self-running, no deps
# or, if you have pytest:
pytest test_services.py
```

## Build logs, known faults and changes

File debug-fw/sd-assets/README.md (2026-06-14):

# Mock QR codes (bench test fixtures)

Generated by `scripts/gen_mock_qr.py` (run with the scripts venv:
`scripts/.venv/bin/python scripts/gen_mock_qr.py`).

| File | Goes where | Purpose |
|---|---|---|
| `qr/MOCK-PART-#####.png` | print / display | one scannable QR per mock part |
| `qr/contact-sheet.png` | print | all codes on one labelled sheet |

## How it's wired

1. The QR payload is exactly the label, e.g. `MOCK-PART-00001`.
2. On the **Load** screen the scanner free-runs at 5 Hz. The first
   recognised code latches in as the part and the UI shows it with
   **Place reel / Rescan / Cancel**.
3. The HMI resolves the scanned code over InvenTree (`resolve_barcode`);
   there is no SD parts catalog anymore. The mock server's `seed.py` has
   eight matching stock items, so these codes exercise the full
   scan → resolve flow on the bench.

To change the set, edit the `PARTS` list in `scripts/gen_mock_qr.py` and
re-run it; the part `id`/`name`/`pkg`/`mfg` mirror the built-in `kCatalog`
in `esp32-hmi/src/ui/app_state.cpp` and the mock seed so scanned parts
line up with rack contents.

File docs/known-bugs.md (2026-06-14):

# Known bugs

Open issues that haven't been fixed yet. Update entries as fixes land
or as we learn more.

---

## HMI: TLS certificate not verified (cert pinning parsed but not enforced)

The HMI's InvenTree client calls `NetworkClientSecure::setInsecure()`
(`esp32-hmi/src/net/inv_api.cpp`), so it does **not** verify the server's
certificate. The provisioning payload (`SRPROV1:`) carries a fingerprint
field (`f`) that the HMI parses but currently ignores. HTTPS traffic is
therefore encrypted but not authenticated — a man-in-the-middle on the LAN
could impersonate the InvenTree/plugin server. Acceptable on the bench (the
mock uses a self-signed cert); **must be fixed before any real deployment**
by enforcing the pinned fingerprint from the provisioning payload (the
server's fingerprint is printed by `debug-fw/mock-inventree/gen-cert.sh`).

**Filed**: 2026-06-13.

---

## HMI: pick-job `status` not persisted across reboot (cache only)

`state_store` writes pick jobs to `/sdcard/jobs.json` but does **not**
persist the per-job `status` field (`pending` / `partial` / `done`). The
status is treated as cache only and is recomputed from the server on the
next pick-job fetch, so a reboot mid-job loses the locally-cached status
until the HMI re-fetches the job list from InvenTree. Already-picked items
are not lost (that state lives server-side); only the local status hint is
transient. Low impact while online; worth persisting if offline job
resumption is ever needed.

**Filed**: 2026-06-12.

---

# Fixed

## ESP32-HMI: screen tearing after WiFi scan populates SSID list

Originally reported on the Configure -> Network screen after a WiFi
scan, then independently reproduced on the Pick Jobs screen near the
job-id labels and anywhere a scrolling list rebuilt. Manifested as
horizontal slices of the LCD shifting sideways for a few scanlines
during a refresh, worse while scrolling.

**Root cause (real one)**: LVGL was configured with two 40-line
partial draw buffers in PSRAM, and `flush_cb` was blitting those
partial regions into the active framebuffer via
`esp_lcd_panel_draw_bitmap`. The RGB DMA was simultaneously scanning
that same framebuffer out to the panel. Whenever LVGL's blit landed
on lines the DMA was about to read, the panel saw mid-update pixels
-- the visible "tear" was the seam between rendered-frame-N and
rendered-frame-N+1.

The IDF-5 bounce buffer fix we shipped earlier addressed a
*different* problem (PSRAM contention starving the DMA's refill
deadline). It didn't help here because the contention here is
*content* (LVGL writes to the same FB the panel is scanning), not
bandwidth.

**Fix (landed)**: switched display.cpp to the canonical Waveshare
"AVOID_TEARING_MODE 1" pattern: full-refresh LVGL + driver-managed
double FB + vsync-gated swap. The two framebuffers the IDF panel
driver allocates (num_fbs=2) are handed to LVGL directly as its
draw buffers; LVGL renders each frame entirely into the inactive
FB; flush_cb requests a buffer swap and blocks until the next
vsync fires (signalled by a semaphore given from the on_vsync ISR)
before letting LVGL reuse the just-departed FB. No partial writes
to the active FB ever happen, so tearing is structurally
impossible.

Confirmed gone on scroll + list rebuild + screen transition.

**Notes for the future**:
- We're now LVGL-bound by the panel refresh rate (~30-40 FPS at our
  16 MHz pclk / 800x480 timings). For an HMI this is plenty; LVGL
  will only redraw when something is dirty.
- If we ever want partial-area updates back for cheaper animation,
  switch to AVOID_TEARING_MODE 3 (direct-mode + dirty-area copy
  between the two FBs). Substantially more complex; not worth it
  unless we see actual frame-time problems.
- The original `lv_obj_clean()` + rebuild churn on Pick Active is no
  longer visible. We can keep the always-dirty marker on
  ConfigNetwork without paying for it.

**Filed**: 2026-05-18.   **Fixed**: 2026-05-19.

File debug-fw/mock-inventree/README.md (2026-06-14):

# mock-inventree

A FastAPI service that mocks the **SmartReel InvenTree plugin** HTTP API. The
HMI talks to this server during development so we can iterate on the
HMI<->plugin contract without standing up real InvenTree. The real plugin will
later implement the same contract by calling InvenTree internally.

The API is **purpose-built for the HMI's workflows** (resolve / assign / pick /
pickjobs / anomaly), not a thin proxy of InvenTree's REST. That keeps the HMI
simple; the plugin does the translation.

## Quick start

```sh
cd debug-fw/mock-inventree
./setup.sh           # creates .venv, installs deps, generates TLS cert (one-off)
./run.sh             # starts on https://0.0.0.0:8443, token "dev-token"
# in another shell:
curl --cacert certs/server.crt \
     -H 'Authorization: Token dev-token' \
     https://localhost:8443/api/v1/health
# or, during dev, skip cert verification with -k:
curl -k -H 'Authorization: Token dev-token' https://localhost:8443/api/v1/health
```

- Status dashboard at <https://localhost:8443/> (auto-redirects to `/ui/`).
- Auto-generated Swagger UI at <https://localhost:8443/docs>.

### Status dashboard

Open `https://<server-host>:8443/` from any browser on the same network -- the
page polls `/api/v1/{health, rack, pickjobs, _dev/anomalies, _dev/ops}` every
2 s and renders the rack as a 4 x 16 grid (click a slot to inspect contents),
plus per-job progress and an anomaly log. The token is read from the input
field at the top and cached in browser localStorage. `/health` is unauth'd so
the heartbeat works even before a token is set.

First time on a new browser: visit the URL, accept the self-signed cert
warning, paste the token, hit Save. Subsequent visits skip both steps.

To reach the dashboard from another machine, look up the server's LAN IP
(e.g. `ip -4 addr | grep inet`) and visit `https://<lan-ip>:8443/`. The cert
generated by `gen-cert.sh` already includes the LAN IP detected at setup
time as a SAN, so cert verification just works -- but most browsers will
still flag self-signed roots; click through the warning once.

### TLS

`./gen-cert.sh` writes a self-signed cert to `certs/server.{crt,key}`. SANs
cover `localhost`, the machine hostname, `127.0.0.1`, `::1`, and the first
non-loopback LAN IPv4 if one is detectable. Valid 825 days; `setup.sh` calls
`gen-cert.sh` and the script no-ops if a valid cert is already in place.

Force a fresh cert: `rm -rf certs/ && ./gen-cert.sh`.

The cert's SHA-256 fingerprint is printed at generation time -- the HMI
client can pin that string instead of installing the cert as a CA. To set
the HMI to skip verification entirely during dev, that's a client-side
config knob (the server doesn't care).

To opt out of TLS during dev: `SR_HTTPS=0 ./run.sh` -> plain HTTP on `:8000`.

### Env vars (all optional)

| Var | Default | Meaning |
|---|---|---|
| `SR_TOKEN` | `dev-token` | required in `Authorization: Token <...>` |
| `SR_HTTPS` | `1` | `0` to serve plain HTTP |
| `SR_PORT`  | `8443` (https) / `8000` (http) | listen port |
| `SR_HOST`  | `0.0.0.0`  | listen address |
| `SR_RACK_LOCATION_ID` | `42` | InvenTree location id the rack registers as |
| `SR_LATENCY_MS` | `0` | inject artificial per-request latency for testing |

## Data model (mock-side)

- **Part**  - catalog entry (`R-10K-0805`, "RES 10kohm 1% 0805", `0805`, Yageo).
- **StockItem**  - a specific reel: id, part, qty, batch, barcode, location_id.
  The thing you actually scan.
- **Location ids** - `42` is the rack; `4201..` are slots underneath it;
  `99` is Staging (picked reels land there); `98` is "pulled / unsorted"
  (anomaly clears land there).
- **PickJob**  - a list of parts to pick (one reel per item). Status is
  derived: pending / partial / done.
- **Anomaly**  - reconciliation event the HMI pushes when its sensors detect
  un-scanned activity.

## API contract  (`/api/v1`)

The contract is specified in **`docs/hmi-plugin-api.md`** (repo root) — that
file is canonical for both this mock and the real plugin in
`inventree-plugin/`. Don't change shapes here without updating it.

Headline semantics (rewritten 2026-06-11 per `docs/user-stories.md`):

- **Picks are whole-reel transfers.** `POST /rack/slots/{n}/pick` takes no
  qty; the slot's StockItem moves to Staging (or `destination_id`) and the
  slot is freed. The old qty-decrement / "Picked bin" model is gone.
- **Pick jobs** come from build orders. One item = one part; picking any
  reel of that part satisfies the item. Job `status` is derived
  (`pending`/`partial`/`done`); there is no cancel endpoint — HMI cancel is
  local and the job stays resumable.
- **`GET /rack`** doubles as the reconciliation source: logically-empty but
  physically-occupied slots mean stock was moved in InvenTree behind our
  back; the HMI lights those slots for manual removal.
- **`GET /_dev/provision`** returns the `SRPROV1:` payload + QR SVG used to
  provision the HMI without typing (dashboard → "Show setup QR").

Run `./smoke-test.sh` after contract changes — it exercises every endpoint
against a throwaway instance.

## Files

```
mock-inventree/
  README.md          # you are here
  setup.sh, run.sh, gen-cert.sh
  requirements.txt
  seed.json          # parts + stock items + initial slot contents + pick jobs
  certs/             # gitignored; self-signed TLS material
  app/
    main.py          # FastAPI app, middleware, lifespan, /ui mount
    config.py        # env-var config
    auth.py          # token dependency
    models.py        # pydantic request/response models
    store.py         # in-memory state, locking, idempotency cache
    seed.py          # deterministic seed builder
    routes/          # one file per resource group
    static/          # dashboard (index.html, style.css, app.js)
```

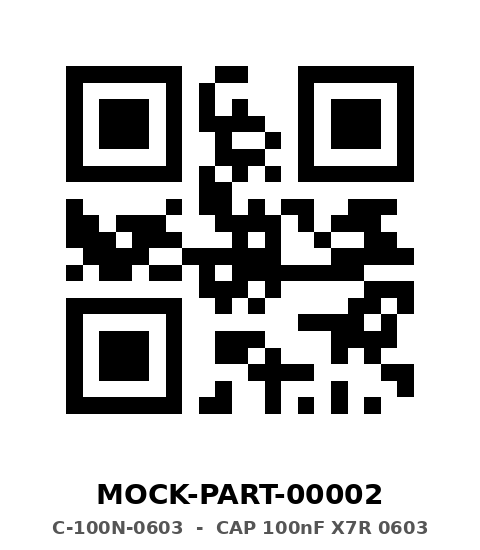
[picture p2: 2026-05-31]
debug-fw/sd-assets/qr/MOCK-PART-00002.png

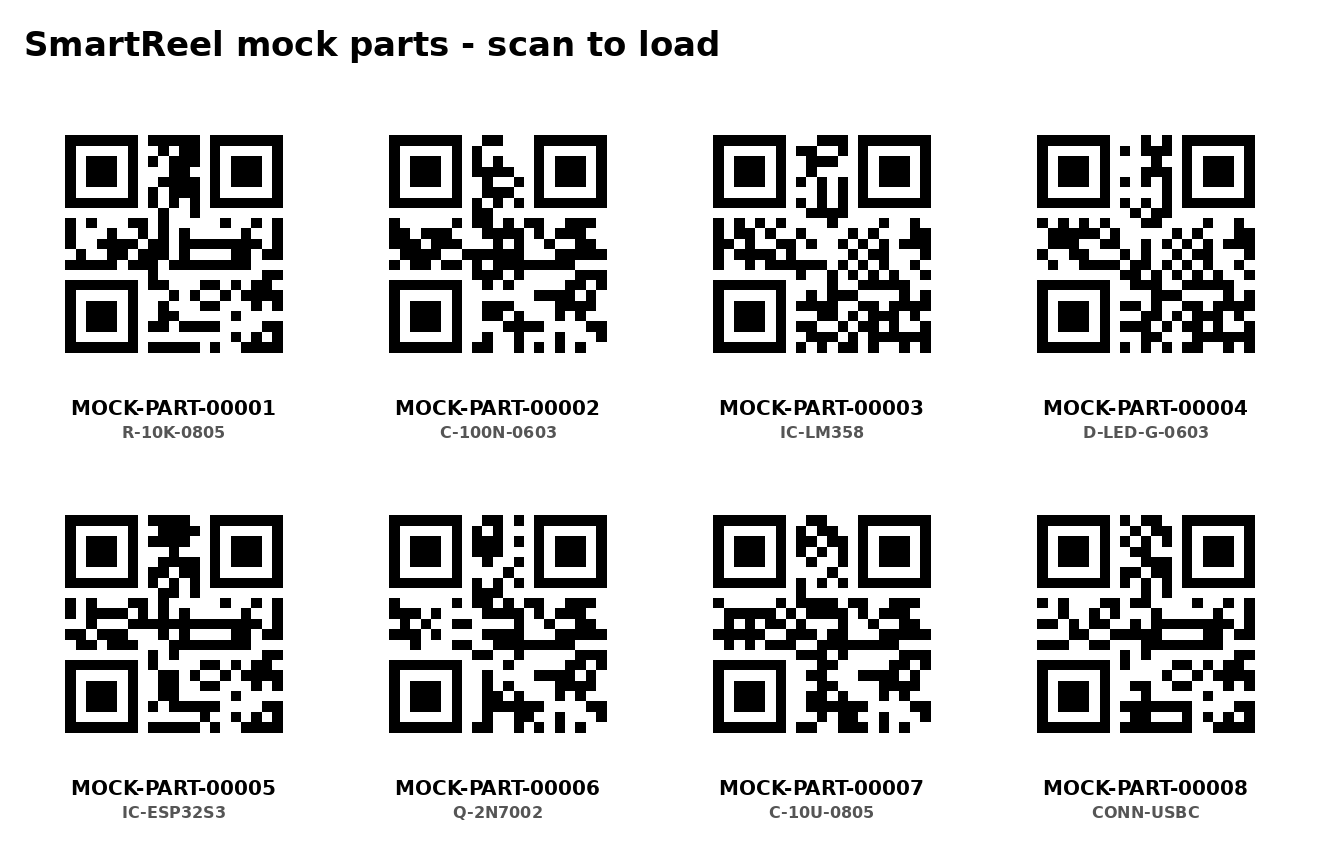
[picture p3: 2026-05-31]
debug-fw/sd-assets/qr/contact-sheet.png

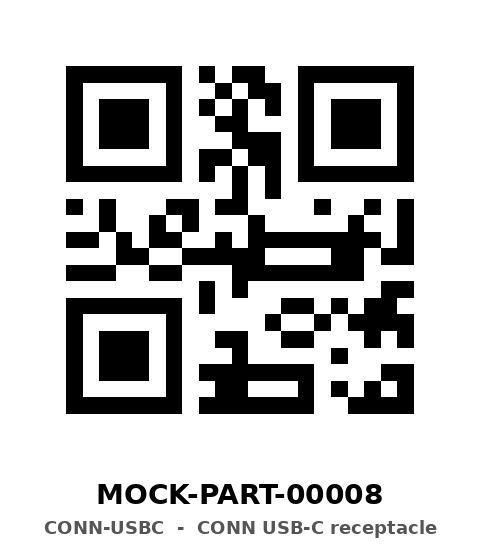
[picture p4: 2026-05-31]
debug-fw/sd-assets/qr/MOCK-PART-00008.png

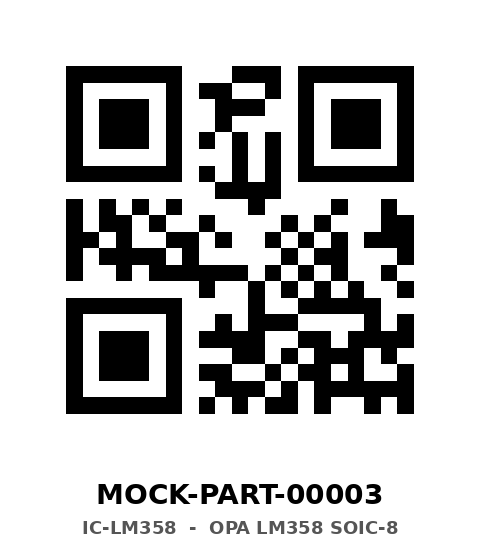
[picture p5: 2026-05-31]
debug-fw/sd-assets/qr/MOCK-PART-00003.png

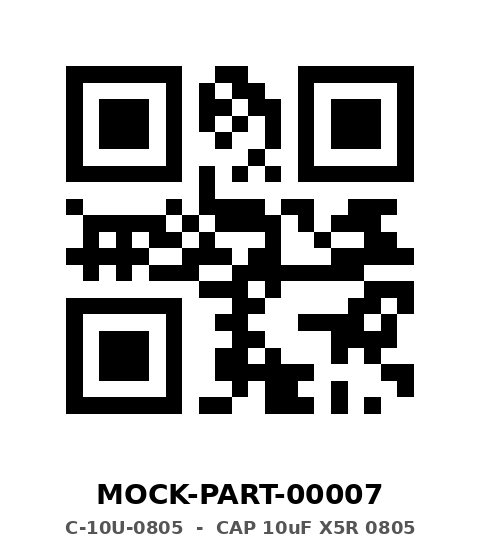
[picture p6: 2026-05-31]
debug-fw/sd-assets/qr/MOCK-PART-00007.png

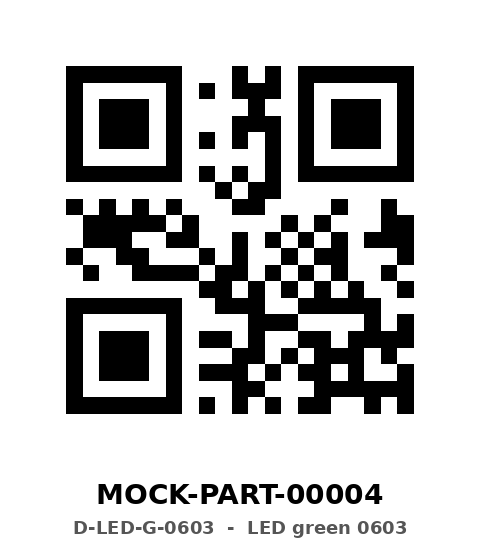
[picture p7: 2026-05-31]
debug-fw/sd-assets/qr/MOCK-PART-00004.png

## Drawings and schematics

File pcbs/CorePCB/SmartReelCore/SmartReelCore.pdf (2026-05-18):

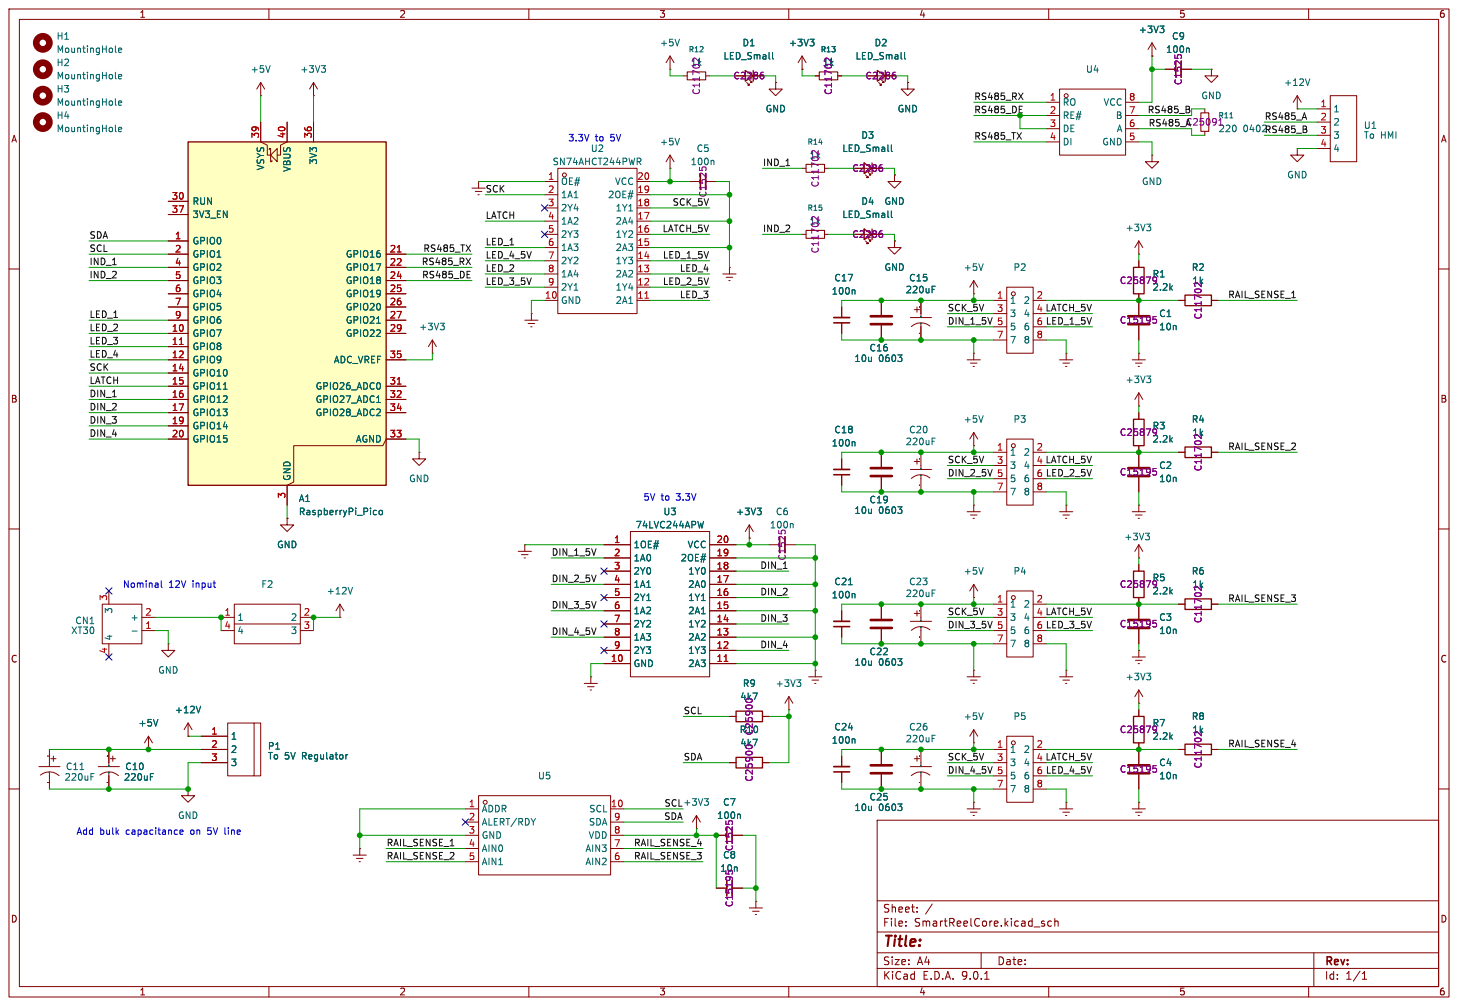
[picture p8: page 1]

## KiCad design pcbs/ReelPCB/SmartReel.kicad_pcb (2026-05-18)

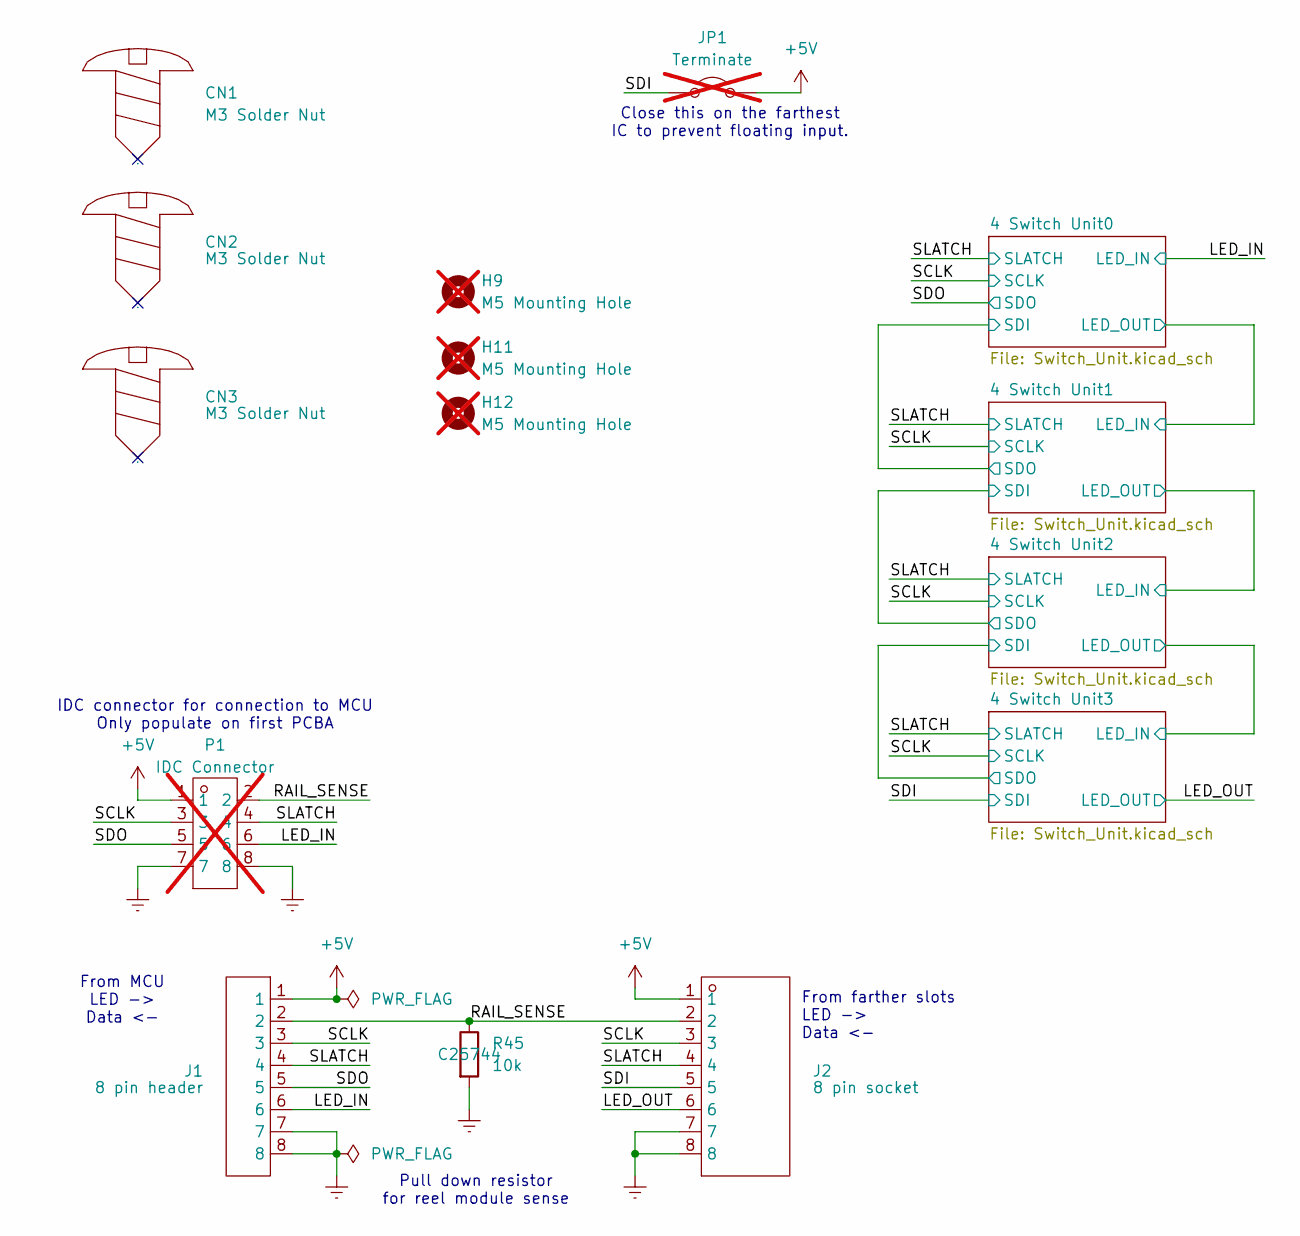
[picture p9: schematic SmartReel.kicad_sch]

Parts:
CN1, CN2, CN3: M3 Solder Nut; M3-TH_BD6.0-D4.3; Manufacturer Part SMTSOM330BTR; LCSC Part Name YIYUAN(怡远) 电路板表贴圆螺母柱 PCB贴片连接器 M3x5.56xL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
H9, H11, H12: M5 Mounting Hole; MountingHole_5.3mm_M5; not fitted
J1: 8 pin header; HDR-TH_8P-P2.54-H-M-W10.0; Manufacturer Part MTP125-1108R1; LCSC Part Name 1x8P 间距:2.54mm 方针 弯插
J2: 8 pin socket; HDR-TH_8P-P2.54-H-W8.6_A2541HWR-8P; Manufacturer Part A2541HWR-8P; LCSC Part Name 1x8P 间距:2.54mm 弯插
JP1: Terminate; SolderJumper-2_P1.3mm_Open_RoundedPad1.0x1.5mm; not fitted
P1: IDC Connector; IDC-TH_8P-P2.00_BOOMELE2X4P; Manufacturer Part 2.0-2*4P直简牛; LCSC Part Name 2mm 2x4P 排数:2 每排P数:4; not fitted
R45: 10k; R_0402_1005Metric

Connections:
+5V: J1.1, J2.1, JP1.2 (B), P1.1; also elsewhere on the board
/LED_IN: J1.6, P1.6; also elsewhere on the board
/LED_OUT: J2.6; also elsewhere on the board
/RAIL_SENSE: J1.2, J2.2, P1.2, R45.1
/SCLK: J1.3, J2.3, P1.3; also elsewhere on the board
/SDI: J2.5, JP1.1 (A); also elsewhere on the board
/SDO: J1.5, P1.5; also elsewhere on the board
/SLATCH: J1.4, J2.4, P1.4; also elsewhere on the board
Earth: J1.7, J1.8, J2.7, J2.8, P1.7, P1.8, R45.2; also elsewhere on the board

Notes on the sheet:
IDC connector for connection to MCU Only populate on first PCBA
Pull down resistor for reel module sense
Close this on the farthest IC to prevent floating input.
From MCU LED -> Data <-
From farther slots LED -> Data <-

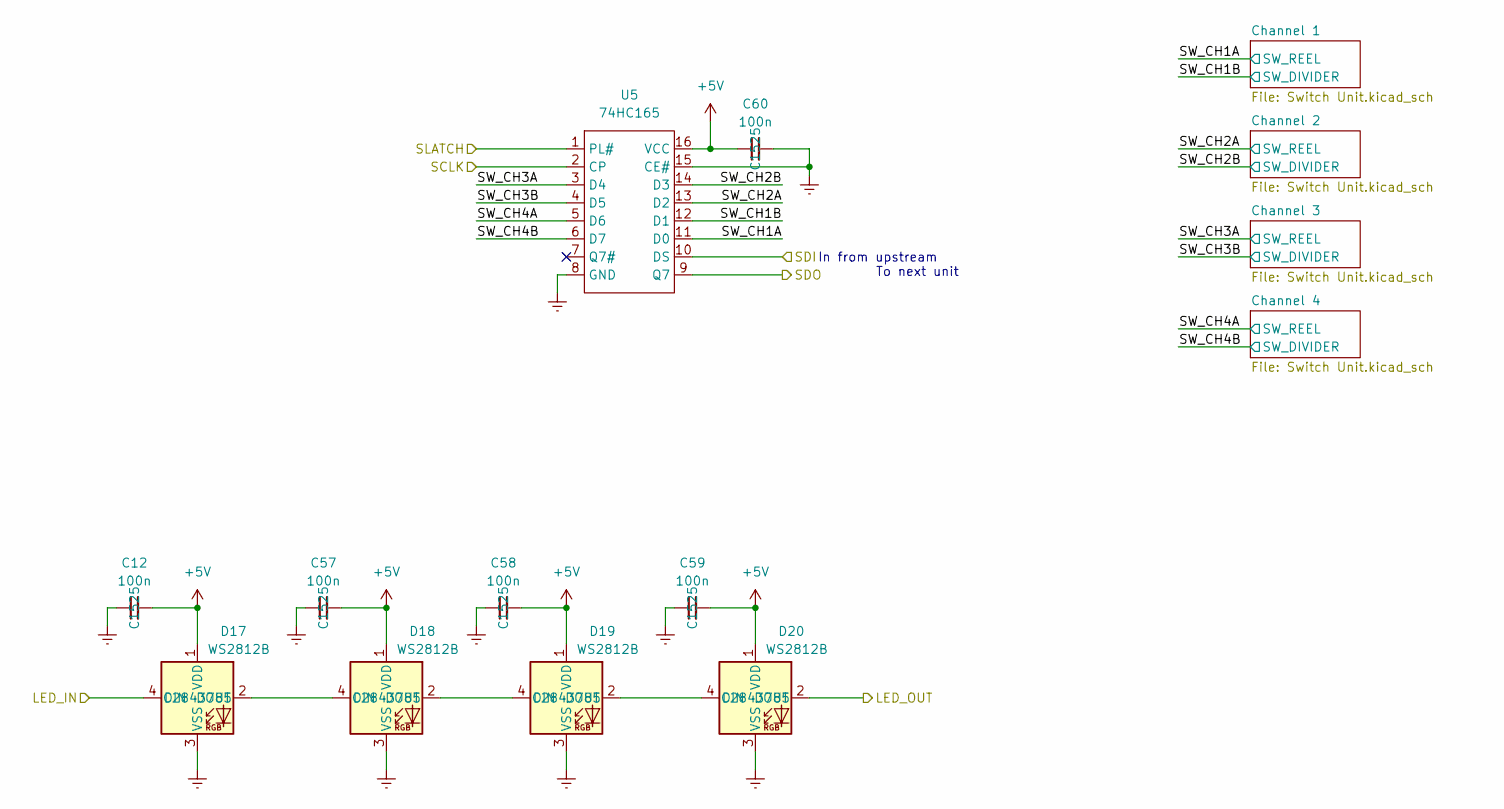
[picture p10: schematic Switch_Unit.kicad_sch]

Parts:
C12, C57, C58, C59, C60: 100n; C_0402_1005Metric
D17, D18, D19, D20: WS2812B; LED_WS2812B_PLCC4_5.0x5.0mm_P3.2mm
U5: 74HC165; SOIC-16_3.9x9.9mm_P1.27mm; Manufacturer Part 74HC165D,653; LCSC Part Name 补充型输出 并行或串行至串行移位寄存器

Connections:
+5V: C12.2, C57.2, C58.2, C59.2, C60.1, D17.1 (VDD), D18.1 (VDD), D19.1 (VDD), D20.1 (VDD), U5.16 (VCC); also elsewhere on the board
/4 Switch Unit0/LED_OUT: D20.2 (DOUT); also elsewhere on the board
/4 Switch Unit0/SDI: U5.10 (DS); also elsewhere on the board
/4 Switch Unit0/SW_CH1A: U5.11 (D0); also elsewhere on the board
/4 Switch Unit0/SW_CH1B: U5.12 (D1); also elsewhere on the board
/4 Switch Unit0/SW_CH2A: U5.13 (D2); also elsewhere on the board
/4 Switch Unit0/SW_CH2B: U5.14 (D3); also elsewhere on the board
/4 Switch Unit0/SW_CH3A: U5.3 (D4); also elsewhere on the board
/4 Switch Unit0/SW_CH3B: U5.4 (D5); also elsewhere on the board
/4 Switch Unit0/SW_CH4A: U5.5 (D6); also elsewhere on the board
/4 Switch Unit0/SW_CH4B: U5.6 (D7); also elsewhere on the board
/LED_IN: D17.4 (DIN); also elsewhere on the board
/SCLK: U5.2 (CP); also elsewhere on the board
/SDO: U5.9 (Q7); also elsewhere on the board
/SLATCH: U5.1 (PL#); also elsewhere on the board
Earth: C12.1, C57.1, C58.1, C59.1, C60.2, D17.3 (VSS), D18.3 (VSS), D19.3 (VSS), D20.3 (VSS), U5.8 (GND), U5.15 (CE#); also elsewhere on the board
unnamed: D17.2 (DOUT), D18.4 (DIN)
unnamed: D18.2 (DOUT), D19.4 (DIN)
unnamed: D19.2 (DOUT), D20.4 (DIN)

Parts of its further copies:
C11, C19, C20, C21, C22, C31, C32, C33, C34, C35, C44, C45, C46, C47, C48: 100n; C_0402_1005Metric
D5, D6, D7, D8, D9, D10, D11, D12, D13, D14, D15, D16: WS2812B; LED_WS2812B_PLCC4_5.0x5.0mm_P3.2mm
U2, U3, U4: 74HC165; SOIC-16_3.9x9.9mm_P1.27mm; Manufacturer Part 74HC165D,653; LCSC Part Name 补充型输出 并行或串行至串行移位寄存器

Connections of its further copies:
+5V: C11.2, C19.2, C20.2, C21.2, C22.1, C31.2, C32.2, C33.2, C34.2, C35.1, C44.2, C45.2, C46.2, C47.2, C48.1, D5.1 (VDD), D6.1 (VDD), D7.1 (VDD), D8.1 (VDD), D9.1 (VDD), D10.1 (VDD), D11.1 (VDD), D12.1 (VDD), D13.1 (VDD), D14.1 (VDD), D15.1 (VDD), D16.1 (VDD), U2.16 (VCC), U3.16 (VCC), U4.16 (VCC); also elsewhere on the board
/4 Switch Unit0/LED_OUT: D5.4 (DIN); also elsewhere on the board
/4 Switch Unit0/SDI: U2.9 (Q7); also elsewhere on the board
/4 Switch Unit1/LED_OUT: D8.2 (DOUT), D9.4 (DIN)
/4 Switch Unit1/SDI: U2.10 (DS), U3.9 (Q7)
/4 Switch Unit1/SW_CH1A: U2.11 (D0); also elsewhere on the board
/4 Switch Unit1/SW_CH1B: U2.12 (D1); also elsewhere on the board
/4 Switch Unit1/SW_CH2A: U2.13 (D2); also elsewhere on the board
/4 Switch Unit1/SW_CH2B: U2.14 (D3); also elsewhere on the board
/4 Switch Unit1/SW_CH3A: U2.3 (D4); also elsewhere on the board
/4 Switch Unit1/SW_CH3B: U2.4 (D5); also elsewhere on the board
/4 Switch Unit1/SW_CH4A: U2.5 (D6); also elsewhere on the board
/4 Switch Unit1/SW_CH4B: U2.6 (D7); also elsewhere on the board
/4 Switch Unit2/LED_OUT: D12.2 (DOUT), D13.4 (DIN)
/4 Switch Unit2/SDI: U3.10 (DS), U4.9 (Q7)
/4 Switch Unit2/SW_CH1A: U3.11 (D0); also elsewhere on the board
/4 Switch Unit2/SW_CH1B: U3.12 (D1); also elsewhere on the board
/4 Switch Unit2/SW_CH2A: U3.13 (D2); also elsewhere on the board
/4 Switch Unit2/SW_CH2B: U3.14 (D3); also elsewhere on the board
/4 Switch Unit2/SW_CH3A: U3.3 (D4); also elsewhere on the board
/4 Switch Unit2/SW_CH3B: U3.4 (D5); also elsewhere on the board
/4 Switch Unit2/SW_CH4A: U3.5 (D6); also elsewhere on the board
/4 Switch Unit2/SW_CH4B: U3.6 (D7); also elsewhere on the board
/4 Switch Unit3/SW_CH1A: U4.11 (D0); also elsewhere on the board
/4 Switch Unit3/SW_CH1B: U4.12 (D1); also elsewhere on the board
/4 Switch Unit3/SW_CH2A: U4.13 (D2); also elsewhere on the board
/4 Switch Unit3/SW_CH2B: U4.14 (D3); also elsewhere on the board
/4 Switch Unit3/SW_CH3A: U4.3 (D4); also elsewhere on the board
/4 Switch Unit3/SW_CH3B: U4.4 (D5); also elsewhere on the board
/4 Switch Unit3/SW_CH4A: U4.5 (D6); also elsewhere on the board
/4 Switch Unit3/SW_CH4B: U4.6 (D7); also elsewhere on the board
/LED_OUT: D16.2 (DOUT); also elsewhere on the board
/SCLK: U2.2 (CP), U3.2 (CP), U4.2 (CP); also elsewhere on the board
/SDI: U4.10 (DS); also elsewhere on the board
/SLATCH: U2.1 (PL#), U3.1 (PL#), U4.1 (PL#); also elsewhere on the board
Earth: C11.1, C19.1, C20.1, C21.1, C22.2, C31.1, C32.1, C33.1, C34.1, C35.2, C44.1, C45.1, C46.1, C47.1, C48.2, D5.3 (VSS), D6.3 (VSS), D7.3 (VSS), D8.3 (VSS), D9.3 (VSS), D10.3 (VSS), D11.3 (VSS), D12.3 (VSS), D13.3 (VSS), D14.3 (VSS), D15.3 (VSS), D16.3 (VSS), U2.8 (GND), U2.15 (CE#), U3.8 (GND), U3.15 (CE#), U4.8 (GND), U4.15 (CE#); also elsewhere on the board
unnamed: D5.2 (DOUT), D6.4 (DIN)
unnamed: D6.2 (DOUT), D7.4 (DIN)
unnamed: D7.2 (DOUT), D8.4 (DIN)
unnamed: D9.2 (DOUT), D10.4 (DIN)
unnamed: D10.2 (DOUT), D11.4 (DIN)
unnamed: D11.2 (DOUT), D12.4 (DIN)
unnamed: D13.2 (DOUT), D14.4 (DIN)
unnamed: D14.2 (DOUT), D15.4 (DIN)
unnamed: D15.2 (DOUT), D16.4 (DIN)

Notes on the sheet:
In from upstream
To next unit

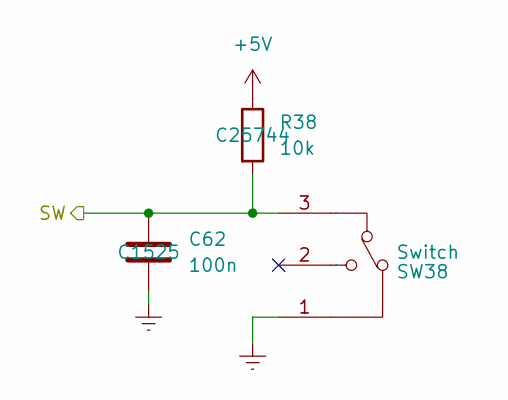
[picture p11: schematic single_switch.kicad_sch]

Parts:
C62: 100n; C_0402_1005Metric
R38: 10k; R_0402_1005Metric
SW38: Switch; SW-TH_SHOU-HAN_3JWD-DBHD-13.5; Manufacturer Part 3JWD-DBHD-13.5 125; LCSC Part Name 鼠标3脚微动 红点直柄13.5

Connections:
+5V: R38.1; also elsewhere on the board
/4 Switch Unit0/SW_CH4B: C62.1, R38.2, SW38.3 (NC); also elsewhere on the board
Earth: C62.2, SW38.1 (C); also elsewhere on the board

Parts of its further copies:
C23, C24, C25, C26, C27, C28, C29, C30, C36, C37, C38, C39, C40, C41, C42, C43, C49, C50, C51, C52, C53, C54, C55, C56, C61, C63, C64, C65, C66, C67, C68: 100n; C_0402_1005Metric
R13, R14, R15, R16, R17, R18, R19, R20, R21, R22, R23, R24, R25, R26, R27, R28, R29, R30, R31, R32, R33, R34, R35, R36, R37, R39, R40, R41, R42, R43, R44: 10k; R_0402_1005Metric
SW13, SW14, SW15, SW16, SW17, SW18, SW19, SW20, SW21, SW22, SW23, SW24, SW25, SW26, SW27, SW28, SW29, SW30, SW31, SW32, SW33, SW34, SW35, SW36, SW37, SW39, SW40, SW41, SW42, SW43, SW44: Switch; SW-TH_SHOU-HAN_3JWD-DBHD-13.5; Manufacturer Part 3JWD-DBHD-13.5 125; LCSC Part Name 鼠标3脚微动 红点直柄13.5

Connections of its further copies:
+5V: R13.1, R14.1, R15.1, R16.1, R17.1, R18.1, R19.1, R20.1, R21.1, R22.1, R23.1, R24.1, R25.1, R26.1, R27.1, R28.1, R29.1, R30.1, R31.1, R32.1, R33.1, R34.1, R35.1, R36.1, R37.1, R39.1, R40.1, R41.1, R42.1, R43.1, R44.1; also elsewhere on the board
/4 Switch Unit0/SW_CH1A: C63.1, R39.2, SW39.3 (NC); also elsewhere on the board
/4 Switch Unit0/SW_CH1B: C64.1, R40.2, SW40.3 (NC); also elsewhere on the board
/4 Switch Unit0/SW_CH2A: C65.1, R41.2, SW41.3 (NC); also elsewhere on the board
/4 Switch Unit0/SW_CH2B: C66.1, R42.2, SW42.3 (NC); also elsewhere on the board
/4 Switch Unit0/SW_CH3A: C67.1, R43.2, SW43.3 (NC); also elsewhere on the board
/4 Switch Unit0/SW_CH3B: C68.1, R44.2, SW44.3 (NC); also elsewhere on the board
/4 Switch Unit0/SW_CH4A: C61.1, R37.2, SW37.3 (NC); also elsewhere on the board
/4 Switch Unit1/SW_CH1A: C25.1, R15.2, SW15.3 (NC); also elsewhere on the board
/4 Switch Unit1/SW_CH1B: C26.1, R16.2, SW16.3 (NC); also elsewhere on the board
/4 Switch Unit1/SW_CH2A: C27.1, R17.2, SW17.3 (NC); also elsewhere on the board
/4 Switch Unit1/SW_CH2B: C28.1, R18.2, SW18.3 (NC); also elsewhere on the board
/4 Switch Unit1/SW_CH3A: C29.1, R19.2, SW19.3 (NC); also elsewhere on the board
/4 Switch Unit1/SW_CH3B: C30.1, R20.2, SW20.3 (NC); also elsewhere on the board
/4 Switch Unit1/SW_CH4A: C23.1, R13.2, SW13.3 (NC); also elsewhere on the board
/4 Switch Unit1/SW_CH4B: C24.1, R14.2, SW14.3 (NC); also elsewhere on the board
/4 Switch Unit2/SW_CH1A: C38.1, R23.2, SW23.3 (NC); also elsewhere on the board
/4 Switch Unit2/SW_CH1B: C39.1, R24.2, SW24.3 (NC); also elsewhere on the board
/4 Switch Unit2/SW_CH2A: C40.1, R25.2, SW25.3 (NC); also elsewhere on the board
/4 Switch Unit2/SW_CH2B: C41.1, R26.2, SW26.3 (NC); also elsewhere on the board
/4 Switch Unit2/SW_CH3A: C42.1, R27.2, SW27.3 (NC); also elsewhere on the board
/4 Switch Unit2/SW_CH3B: C43.1, R28.2, SW28.3 (NC); also elsewhere on the board
/4 Switch Unit2/SW_CH4A: C36.1, R21.2, SW21.3 (NC); also elsewhere on the board
/4 Switch Unit2/SW_CH4B: C37.1, R22.2, SW22.3 (NC); also elsewhere on the board
/4 Switch Unit3/SW_CH1A: C51.1, R31.2, SW31.3 (NC); also elsewhere on the board
/4 Switch Unit3/SW_CH1B: C52.1, R32.2, SW32.3 (NC); also elsewhere on the board
/4 Switch Unit3/SW_CH2A: C53.1, R33.2, SW33.3 (NC); also elsewhere on the board
/4 Switch Unit3/SW_CH2B: C54.1, R34.2, SW34.3 (NC); also elsewhere on the board
/4 Switch Unit3/SW_CH3A: C55.1, R35.2, SW35.3 (NC); also elsewhere on the board
/4 Switch Unit3/SW_CH3B: C56.1, R36.2, SW36.3 (NC); also elsewhere on the board
/4 Switch Unit3/SW_CH4A: C49.1, R29.2, SW29.3 (NC); also elsewhere on the board
/4 Switch Unit3/SW_CH4B: C50.1, R30.2, SW30.3 (NC); also elsewhere on the board
Earth: C23.2, C24.2, C25.2, C26.2, C27.2, C28.2, C29.2, C30.2, C36.2, C37.2, C38.2, C39.2, C40.2, C41.2, C42.2, C43.2, C49.2, C50.2, C51.2, C52.2, C53.2, C54.2, C55.2, C56.2, C61.2, C63.2, C64.2, C65.2, C66.2, C67.2, C68.2, SW13.1 (C), SW14.1 (C), SW15.1 (C), SW16.1 (C), SW17.1 (C), SW18.1 (C), SW19.1 (C), SW20.1 (C), SW21.1 (C), SW22.1 (C), SW23.1 (C), SW24.1 (C), SW25.1 (C), SW26.1 (C), SW27.1 (C), SW28.1 (C), SW29.1 (C), SW30.1 (C), SW31.1 (C), SW32.1 (C), SW33.1 (C), SW34.1 (C), SW35.1 (C), SW36.1 (C), SW37.1 (C), SW39.1 (C), SW40.1 (C), SW41.1 (C), SW42.1 (C), SW43.1 (C), SW44.1 (C); also elsewhere on the board

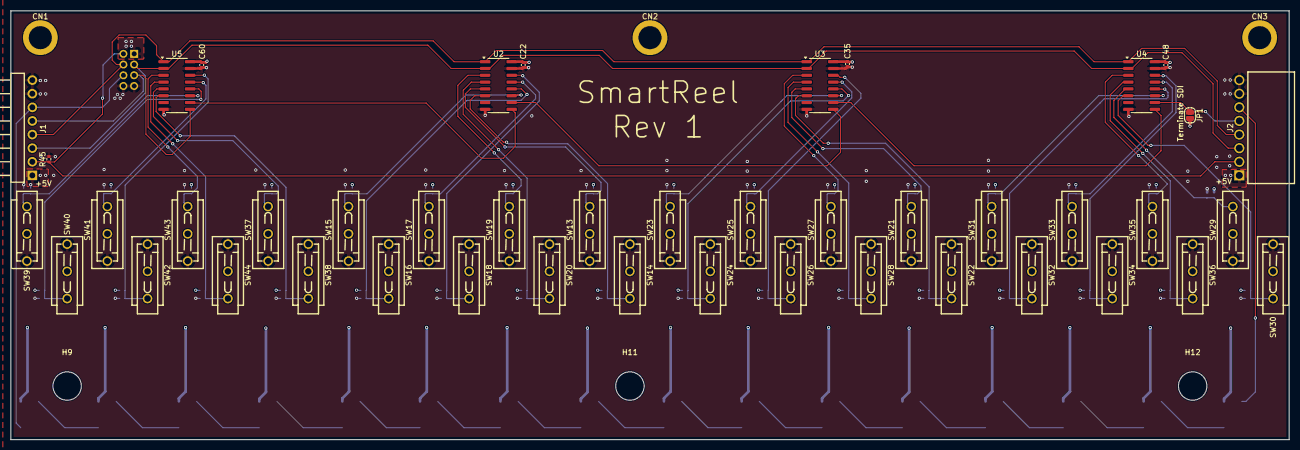
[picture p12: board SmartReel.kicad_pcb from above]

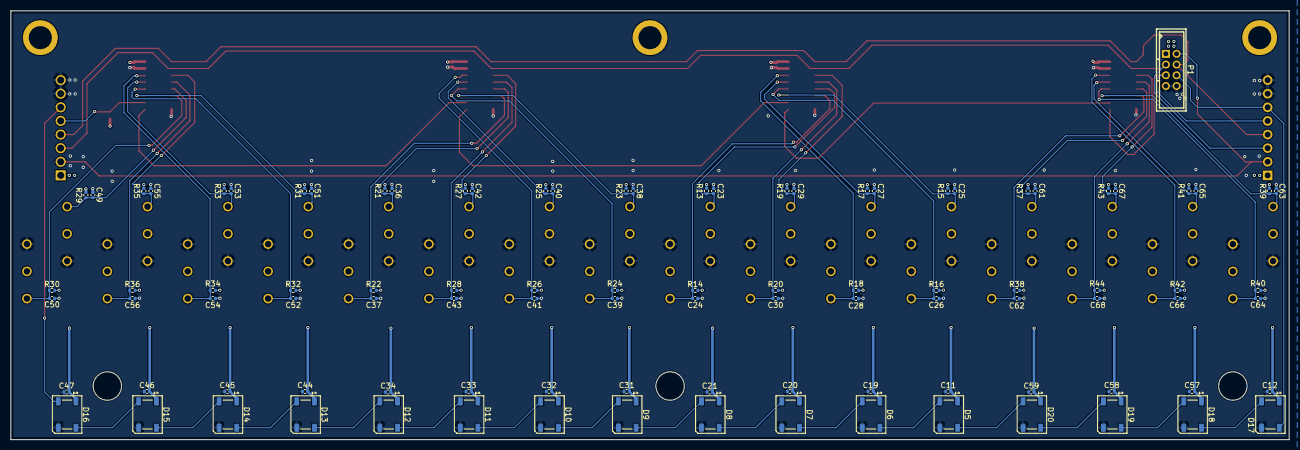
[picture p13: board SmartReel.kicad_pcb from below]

Board: 4 copper layers, 238.5 x 80.0 mm, 147 parts (97 on the bottom side), 59 nets.

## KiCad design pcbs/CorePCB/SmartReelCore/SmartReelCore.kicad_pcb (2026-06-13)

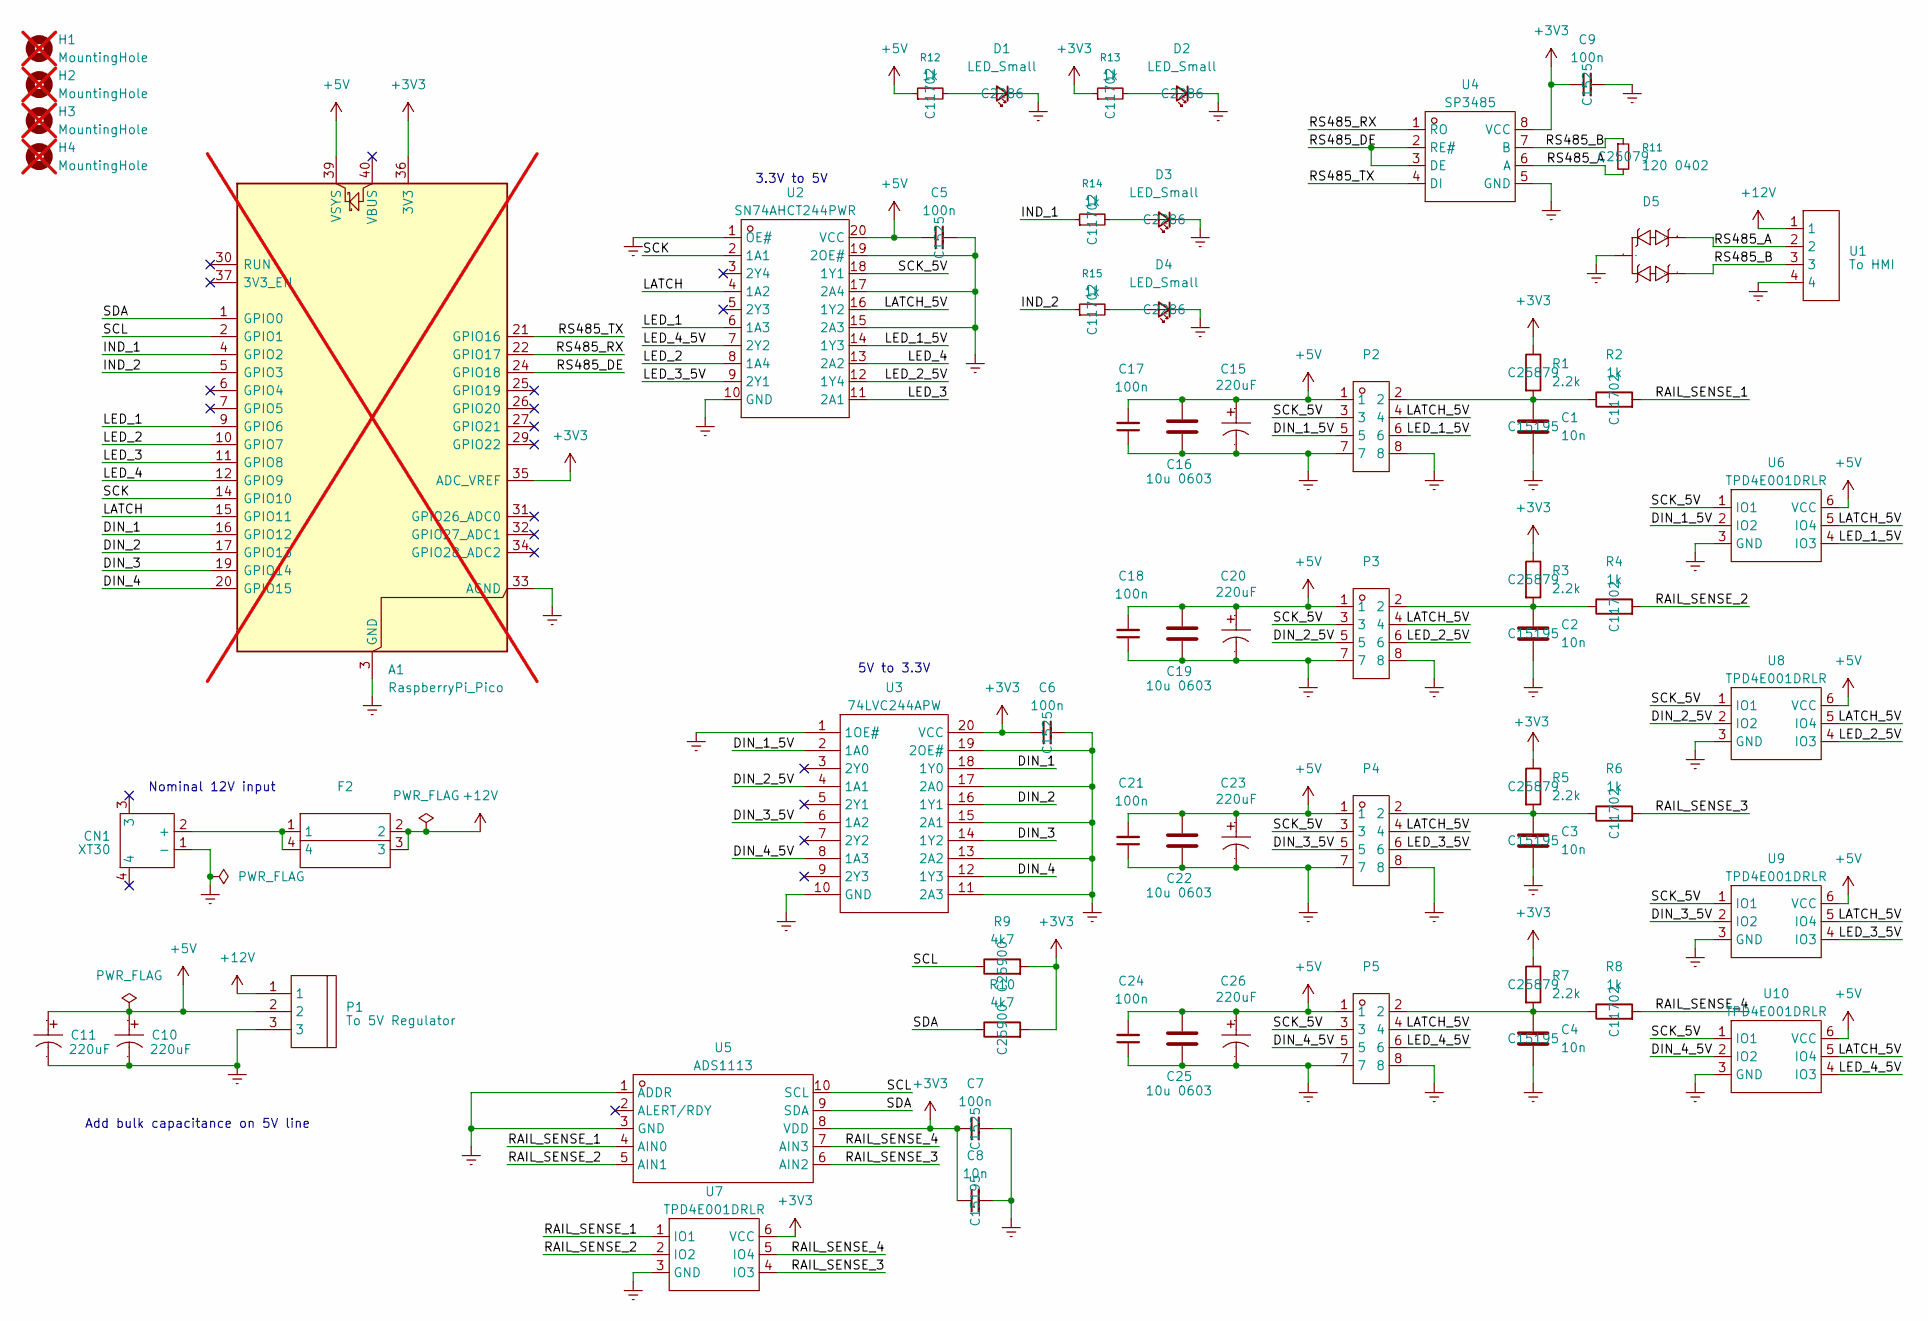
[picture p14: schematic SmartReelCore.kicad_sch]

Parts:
A1: RaspberryPi_Pico; RaspberryPi_Pico_Common_Unspecified; not fitted
C1, C2, C3, C4, C8: 10n; C_0402_1005Metric
C5, C6, C7, C9, C17, C18, C21, C24: 100n; C_0402_1005Metric
C10, C11, C15, C20, C23, C26: 220uF; CAP-SMD_BD8.0-L8.3-W8.3-LS9.3-FD; Manufacturer Part RVT1V221M0810; LCSC Part Name 220uF ±20% 35V
C16, C19, C22, C25: 10u 0603; C_0603_1608Metric
CN1: XT30; CONN-TH_XT30PW-M; Manufacturer Part XT30PW-M30.G.Y; LCSC Part Name AMASS(艾迈斯)航模插头电调机插座锂电池连接器 PCB板卧式 公头XT30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
D1, D2, D3, D4: LED_Small; LED_0603_1608Metric
D5: SOT-23-3_L2.9-W1.3-P1.90-LS2.4-BR; Manufacturer Part SM712-02HTG; LCSC Part Name SM712-02HTG
F2: FUSE-TH_4P-L16.0-W6.7; Manufacturer Part XF-508P-B-B; LCSC Part Name 汽车保险丝座 小号
H1, H2, H3, H4: MountingHole; MountingHole_3.2mm_M3_Pad; not fitted
P1: To 5V Regulator; CONN-TH_3P-P5.00_WJ500V-5.08-3P; Manufacturer Part WJ500V-5.08-03P-14-00A; LCSC Part Name 5.08mm 1x3P 排数:1 每排P数:3 直插
P2, P3, P4, P5: IDC-TH_8P-P2.00_BOOMELE2X4P; Manufacturer Part 2.0-2*4P直简牛; LCSC Part Name 2mm 2x4P 排数:2 每排P数:4
R1, R3, R5, R7: 2.2k; R_0402_1005Metric
R2, R4, R6, R8, R12, R13, R14, R15: 1k; R_0402_1005Metric
R9, R10: 4k7; R_0402_1005Metric
R11: 120 0402; R_0402_1005Metric
U1: To HMI; CONN-TH_WJ500V-5.08-4P; Manufacturer Part WJ500V-5.08-04P-14-00A; LCSC Part Name 5.08mm 直插 排数:1 每排P数:4
U2: SN74AHCT244PWR; TSSOP-20_L6.5-W4.4-P0.65-LS6.4-BL; Manufacturer Part SN74AHCT244PWR; LCSC Part Name SN74AHCT244PWR
U3: 74LVC244APW; TSSOP-20_L6.5-W4.4-P0.65-LS6.4-BL; Manufacturer Part 74LVC244APW,118; LCSC Part Name 三态输出，八路缓冲器/线路驱动器
U4: SP3485; SOIC-8_L5.0-W4.0-P1.27-LS6.0-BL; Manufacturer Part SP3485EN-L/TR; LCSC Part Name SP3485 +3.3V低功耗半双工RS-485收发器，数据速率10Mbps
U5: ADS1113; VSSOP-10_L3.0-W3.0-P0.50-LS4.9-BL; Manufacturer Part ADS1115IDGST; LCSC Part Name 具有内部基准、振荡器和可编程比较器且兼容 I2C 的ADS111x、超小型、低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
U6, U7, U8, U9, U10: TPD4E001DRLR; SOT-563_L1.6-W1.2-P0.50-LS1.6-BL; Manufacturer Part TPD4E001DRLR; LCSC Part Name 低电容TVS二极管

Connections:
+3V3: A1.35 (ADC_VREF), A1.36 (3V3), C6.1, C7.1, C8.1, C9.1, R1.1, R3.1, R5.1, R7.1, R9.2, R10.2, R13.1, U3.20 (VCC), U4.8 (VCC), U5.8 (VDD), U7.6 (VCC)
+5V: A1.39 (VSYS), C5.1, C10.1, C11.1, C15.1, C16.1, C17.2, C18.2, C19.1, C20.1, C21.2, C22.1, C23.1, C24.2, C25.1, C26.1, P1.2, P2.1, P3.1, P4.1, P5.1, R12.1, U2.20 (VCC), U6.6 (VCC), U8.6 (VCC), U9.6 (VCC), U10.6 (VCC)
+12V: F2.2, F2.3, P1.1, U1.1
/DIN_1: A1.16 (GPIO12), U3.18 (1Y0)
/DIN_1_5V: P2.5, U3.2 (1A0), U6.2 (IO2)
/DIN_2: A1.17 (GPIO13), U3.16 (1Y1)
/DIN_2_5V: P3.5, U3.4 (1A1), U8.2 (IO2)
/DIN_3: A1.19 (GPIO14), U3.14 (1Y2)
/DIN_3_5V: P4.5, U3.6 (1A2), U9.2 (IO2)
/DIN_4: A1.20 (GPIO15), U3.12 (1Y3)
/DIN_4_5V: P5.5, U3.8 (1A3), U10.2 (IO2)
/IND_1: A1.4 (GPIO2), R14.1
/IND_2: A1.5 (GPIO3), R15.1
/LATCH: A1.15 (GPIO11), U2.4 (1A2)
/LATCH_5V: P2.4, P3.4, P4.4, P5.4, U2.16 (1Y2), U6.5 (IO4), U8.5 (IO4), U9.5 (IO4), U10.5 (IO4)
/LED_1: A1.9 (GPIO6), U2.6 (1A3)
/LED_1_5V: P2.6, U2.14 (1Y3), U6.4 (IO3)
/LED_2: A1.10 (GPIO7), U2.8 (1A4)
/LED_2_5V: P3.6, U2.12 (1Y4), U8.4 (IO3)
/LED_3: A1.11 (GPIO8), U2.11 (2A1)
/LED_3_5V: P4.6, U2.9 (2Y1), U9.4 (IO3)
/LED_4: A1.12 (GPIO9), U2.13 (2A2)
/LED_4_5V: P5.6, U2.7 (2Y2), U10.4 (IO3)
/RAIL_SENSE_1: R2.2, U5.4 (AIN0), U7.1 (IO1)
/RAIL_SENSE_2: R4.2, U5.5 (AIN1), U7.2 (IO2)
/RAIL_SENSE_3: R6.2, U5.6 (AIN2), U7.4 (IO3)
/RAIL_SENSE_4: R8.2, U5.7 (AIN3), U7.5 (IO4)
/RS485_A: D5.1, R11.2, U1.2, U4.6 (A)
/RS485_B: D5.2, R11.1, U1.3, U4.7 (B)
/RS485_DE: A1.24 (GPIO18), U4.2 (RE#), U4.3 (DE)
/RS485_RX: A1.22 (GPIO17), U4.1 (RO)
/RS485_TX: A1.21 (GPIO16), U4.4 (DI)
/SCK: A1.14 (GPIO10), U2.2 (1A1)
/SCK_5V: P2.3, P3.3, P4.3, P5.3, U2.18 (1Y1), U6.1 (IO1), U8.1 (IO1), U9.1 (IO1), U10.1 (IO1)
/SCL: A1.2 (GPIO1), R9.1, U5.10 (SCL)
/SDA: A1.1 (GPIO0), R10.1, U5.9 (SDA)
Earth: A1.3 (GND), A1.8 (GND), A1.13 (GND), A1.18 (GND), A1.23 (GND), A1.28 (GND), A1.33 (AGND), A1.38 (GND), C1.2, C2.2, C3.2, C4.2, C5.2, C6.2, C7.2, C8.2, C9.2, C10.2, C11.2, C15.2, C16.2, C17.1, C18.1, C19.2, C20.2, C21.1, C22.2, C23.2, C24.1, C25.2, C26.2, CN1.1 (-), D1.1 (K), D2.1 (K), D3.1 (K), D4.1 (K), D5.3, P1.3, P2.7, P2.8, P3.7, P3.8, P4.7, P4.8, P5.7, P5.8, U1.4, U2.1 (OE#), U2.10 (GND), U2.15 (2A3), U2.17 (2A4), U2.19 (2OE#), U3.1 (1OE#), U3.10 (GND), U3.11 (2A3), U3.13 (2A2), U3.15 (2A1), U3.17 (2A0), U3.19 (2OE#), U4.5 (GND), U5.1 (ADDR), U5.3 (GND), U6.3 (GND), U7.3 (GND), U8.3 (GND), U9.3 (GND), U10.3 (GND)
unnamed: C1.1, P2.2, R1.2, R2.1
unnamed: C2.1, P3.2, R3.2, R4.1
unnamed: C3.1, P4.2, R5.2, R6.1
unnamed: C4.1, P5.2, R7.2, R8.1
unnamed: CN1.2 (+), F2.1, F2.4
unnamed: D1.2 (A), R12.2
unnamed: D2.2 (A), R13.2
unnamed: D3.2 (A), R14.2
unnamed: D4.2 (A), R15.2

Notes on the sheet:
Add bulk capacitance on 5V line
Nominal 12V input
3.3V to 5V
5V to 3.3V

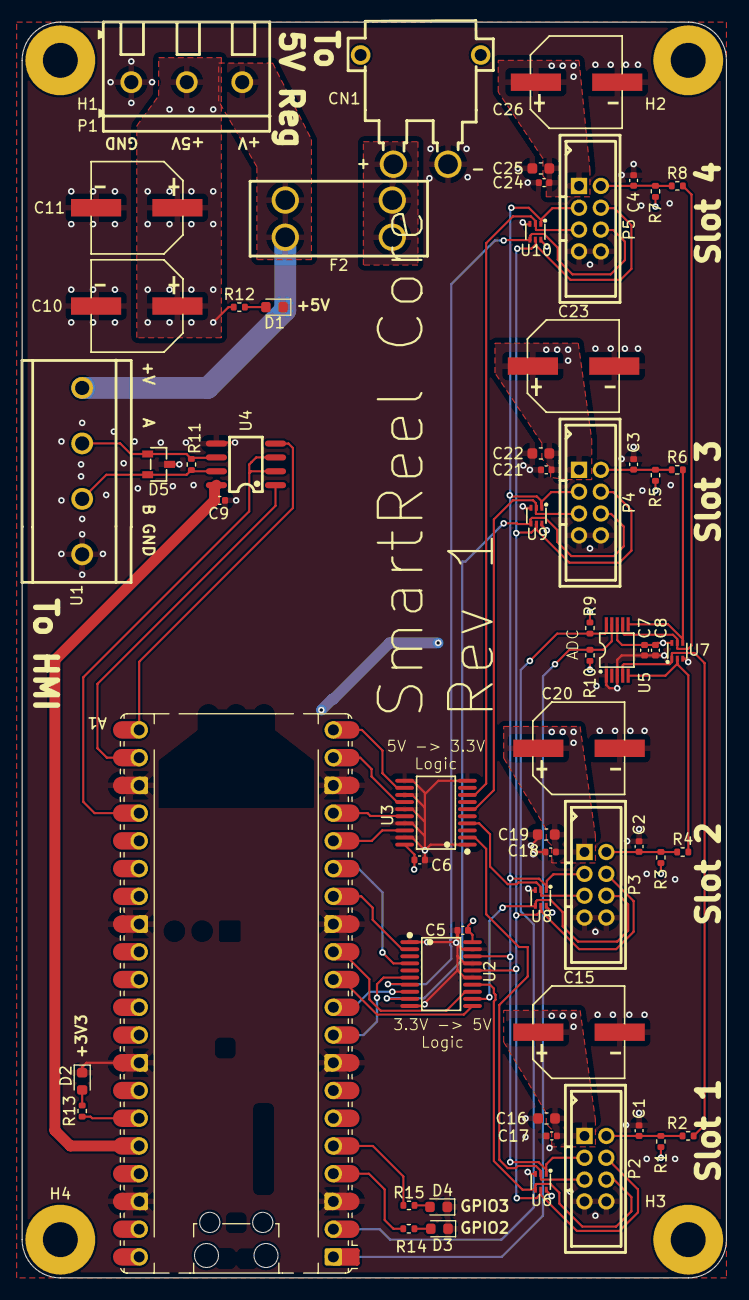
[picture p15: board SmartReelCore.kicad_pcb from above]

Board: 4 copper layers, 64.5 x 115.0 mm, 65 parts (0 on the bottom side), 46 nets.

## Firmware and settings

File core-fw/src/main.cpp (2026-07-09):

// =====================================================================
//  SmartReel Core -- production firmware (RP2040)
//
//  The real core firmware. It drives the Core PCB's slot hardware
//  (WS2812B LEDs, ADS1115 reel-sense, 74HC165 inputs -- see reel_hw.*)
//  and speaks the slave half of docs/smartreel-rs485-protocol.md to the
//  ESP32 HMI bus master.
//
//  Hardware model (see config.h): four PORTS, each carrying 1..4 chained
//  reel MODULES (16 LEDs + 32 input bits each). Module count per port is
//  sensed from a voltage divider.
//
//  Loop structure: service the RS485 link first (replies sent inline as
//  each request decodes), then run the input sampler (~100 Hz) and the
//  sense sampler (round-robin), then refresh the debug LEDs. No blocking
//  calls on the hot path, so request latency stays under the HMI's
//  ~50 ms transaction timeout. Hardware sampling is suspended during a
//  firmware update (flash writes disable XIP / interrupts).
//
//  Serial   -- USB CDC operator/diagnostic console (type 'help').
//  Serial1  -- UART0, the SP3485 RS485 link to the HMI.
// =====================================================================

#include <Arduino.h>
#include <Updater.h>
#include <LittleFS.h>
#include <string.h>
#include <stdlib.h>

#include "config.h"
#include "reel_hw.h"
#include "rs485/rs485_proto.h"
#include "rs485/rs485_frame.h"
#include "sha256.h"
#include "fw_tag.h"

using namespace rs485;

// Semantic version comes from -DFW_VER_* (platformio.ini). The embedded
// tag lets the HMI read this version out of core.bin on the SD card.
FW_TAG_DEFINE("core");

#define CORE_BUILD_TAG "prod"
#define RS485 Serial1

// ---- Diagnostics ---------------------------------------------------
static uint32_t s_boot_ms = 0;
static uint16_t s_error_flags = 0;
static uint32_t s_rx_frames = 0, s_tx_frames = 0, s_polls = 0;
static uint32_t s_rx_bytes  = 0;
static uint32_t s_last_master_ms = 0;   // last valid frame addressed to us

// ---- Async event ring ----------------------------------------------
// Events live here until the HMI ACKs their SEQ (MSG_ACK_EVENTS). Until
// then every POLL re-reports them -- the resend behaviour the protocol
// doc calls for.
struct PendingEvt {
    bool    used;
    uint8_t seq;
    uint8_t type;
    uint8_t len;
    uint8_t data[64];
};
static constexpr int EVT_RING = 32;
static PendingEvt s_evt[EVT_RING];
static uint8_t    s_evt_seq = 1;   // 0 is reserved

static uint8_t next_evt_seq() {
    uint8_t s = s_evt_seq++;
    if (s_evt_seq == 0) s_evt_seq = 1;
    return s;
}

static bool enqueue_event(uint8_t type, const uint8_t* data, uint8_t len) {
    if (len > sizeof(((PendingEvt*)0)->data)) len = sizeof(((PendingEvt*)0)->data);
    for (int i = 0; i < EVT_RING; ++i) {
        if (!s_evt[i].used) {
            s_evt[i].used = true;
            s_evt[i].seq  = next_evt_seq();
            s_evt[i].type = type;
            s_evt[i].len  = len;
            if (len) memcpy(s_evt[i].data, data, len);
            return true;
        }
    }
    Serial.println("[evt] ring full -- event dropped (HMI not ACKing?)");
    return false;
}

static void ack_event_seq(uint8_t seq) {
    for (int i = 0; i < EVT_RING; ++i)
        if (s_evt[i].used && s_evt[i].seq == seq) { s_evt[i].used = false; return; }
}

// ---- byte helpers --------------------------------------------------
static uint32_t be32(const uint8_t* p) {
    return ((uint32_t)p[0] << 24) | ((uint32_t)p[1] << 16) |
           ((uint32_t)p[2] << 8)  |  (uint32_t)p[3];
}
static void put_be32(uint8_t* p, uint32_t v) {
    p[0] = v >> 24; p[1] = v >> 16; p[2] = v >> 8; p[3] = v;
}
static void put_be16(uint8_t* p, uint16_t v) { p[0] = v >> 8; p[1] = v; }

// ---- Debug LED activity blip ---------------------------------------
static uint32_t s_aux_until = 0;
static inline void aux_blip(uint32_t ms = 40) { s_aux_until = millis() + ms; }

// =====================================================================
//  Hardware -> RS485 event bridge (callbacks from reel_hw sampling)
// =====================================================================
static void on_input_change(uint8_t port, uint8_t module,
                            uint32_t prev, uint32_t now) {
    uint8_t d[14];
    d[0] = port;
    d[1] = module;
    put_be32(&d[2],  prev);
    put_be32(&d[6],  now);
    put_be32(&d[10], millis());
    enqueue_event(EVT_INPUT_CHANGE, d, sizeof(d));
    aux_blip();
}

static void on_module_count(uint8_t port, uint8_t prev_count,
                            uint8_t now_count, uint16_t sense_mv) {
    if (now_count > prev_count) {
        uint8_t d[4] = { port, now_count, 0, 0 };
        put_be16(&d[2], sense_mv);
        enqueue_event(EVT_REEL_INSERTED, d, sizeof(d));
    } else if (now_count < prev_count) {
        uint8_t d[2] = { port, now_count };
        enqueue_event(EVT_REEL_REMOVED, d, sizeof(d));
    }
    aux_blip();
}

// =====================================================================
//  RS485 transmit (half-duplex turnaround)
// =====================================================================
static uint8_t s_txbuf[MAX_FRAME_BYTES];

static void rs485_send(uint8_t type, uint8_t seq,
                       const uint8_t* payload, size_t plen) {
    size_t n = encode_frame(s_txbuf, sizeof(s_txbuf),
                            ADDR_MASTER, seq, type, payload, plen);
    if (!n) return;
    // Turnaround: the HMI's auto-direction transceiver needs a moment to
    // switch drive->receive after sending. Reply too soon and it misses
    // the start of our frame (master-side timeout, no CRC error).
    delayMicroseconds(500);
    digitalWrite(cfg::PIN_RS485_DE, HIGH);
    RS485.write(s_txbuf, n);
    RS485.flush();                  // drains TX FIFO (not the shift reg)
    // Hold DE until the final byte fully shifts out: 10 bits/115200 ~= 87us.
    delayMicroseconds(200);
    digitalWrite(cfg::PIN_RS485_DE, LOW);
    s_tx_frames++;
}

static void send_ack(uint8_t req_type, uint8_t seq) {
    rs485_send(mk_response(req_type), seq, nullptr, 0);
}
static void send_error(uint8_t req_type, uint8_t seq, uint8_t err) {
    rs485_send(mk_error_response(req_type), seq, &err, 1);
}

// =====================================================================
//  Request handlers (slave side)
// =====================================================================
static void handle_poll(uint8_t seq) {
    s_polls++;
    uint8_t buf[MAX_PAYLOAD];
    size_t  off = 1;            // reserve byte 0 for count
    uint8_t count = 0;
    for (int i = 0; i < EVT_RING; ++i) {
        if (!s_evt[i].used) continue;
        const size_t need = 3 + s_evt[i].len;
        if (off + need > sizeof(buf)) break;
        buf[off++] = s_evt[i].type;
        buf[off++] = s_evt[i].seq;
        buf[off++] = s_evt[i].len;
        if (s_evt[i].len) { memcpy(&buf[off], s_evt[i].data, s_evt[i].len); off += s_evt[i].len; }
        count++;
    }
    buf[0] = count;
    rs485_send(mk_response(MSG_POLL), seq, buf, off);
}

static void handle_ack_events(uint8_t seq, const uint8_t* p, size_t len) {
    if (len < 1) { send_error(MSG_ACK_EVENTS, seq, ERR_BAD_PAYLOAD); return; }
    uint8_t n = p[0];
    for (uint8_t i = 0; i < n && (size_t)(1 + i) < len; ++i) ack_event_seq(p[1 + i]);
    send_ack(MSG_ACK_EVENTS, seq);
}

static void handle_get_version(uint8_t seq) {
    const uint8_t v[8] = { g_fw_tag.major, g_fw_tag.minor, g_fw_tag.patch,
                           0, 0, 0, 0, 0x01 /*hw_rev*/ };
    rs485_send(mk_response(MSG_GET_VERSION), seq, v, sizeof(v));
}

static void handle_get_status(uint8_t seq) {
    uint32_t up = (millis() - s_boot_ms) / 1000;
    uint8_t v[7];
    put_be32(&v[0], up);
    v[4] = reel_hw::reels_present_bitmap();
    put_be16(&v[5], s_error_flags);
    rs485_send(mk_response(MSG_GET_STATUS), seq, v, sizeof(v));
}

// One GET_REEL_INFO record: port, present, sense_mv(2 BE), module_count.
static void append_reel_record(uint8_t* buf, size_t& off, uint8_t p) {
    const reel_hw::PortState& st = reel_hw::port(p);
    buf[off++] = p;
    buf[off++] = st.module_count > 0 ? 1 : 0;
    put_be16(&buf[off], st.sense_mv); off += 2;
    buf[off++] = st.module_count;
}

static void handle_get_reel_info(uint8_t seq, const uint8_t* p, size_t len) {
    if (len < 1) { send_error(MSG_GET_REEL_INFO, seq, ERR_BAD_PAYLOAD); return; }
    uint8_t port = p[0];
    uint8_t buf[MAX_PAYLOAD];
    size_t  off = 1;
    uint8_t count = 0;
    if (port == REEL_ID_ALL) {
        for (uint8_t r = 0; r < cfg::N_PORTS; ++r) { append_reel_record(buf, off, r); count++; }
    } else if (port < cfg::N_PORTS) {
        append_reel_record(buf, off, port); count = 1;
    } else {
        send_error(MSG_GET_REEL_INFO, seq, ERR_REEL_ABSENT); return;
    }
    buf[0] = count;
    rs485_send(mk_response(MSG_GET_REEL_INFO), seq, buf, off);
}

// READ_INPUTS(port): port, module_count, {u32 BE} x module_count.
static void handle_read_inputs(uint8_t seq, const uint8_t* p, size_t len) {
    if (len < 1) { send_error(MSG_READ_INPUTS, seq, ERR_BAD_PAYLOAD); return; }
    uint8_t port = p[0];
    if (port >= cfg::N_PORTS) { send_error(MSG_READ_INPUTS, seq, ERR_REEL_ABSENT); return; }
    const reel_hw::PortState& st = reel_hw::port(port);
    uint8_t buf[2 + cfg::MAX_MODULES_PER_PORT * 4];
    size_t  off = 0;
    buf[off++] = port;
    buf[off++] = st.module_count;
    for (uint8_t m = 0; m < st.module_count && m < cfg::MAX_MODULES_PER_PORT; ++m) {
        put_be32(&buf[off], st.inputs[m]); off += 4;
    }
    rs485_send(mk_response(MSG_READ_INPUTS), seq, buf, off);
}

// ---- LED control ---------------------------------------------------
// SET_REEL_PIXELS stages into the back buffer (atomic multi-port shows
// land on COMMIT). FILL_REEL and SET_BRIGHTNESS apply immediately --
// they're commonly used standalone -- by committing the affected port.
static void handle_set_reel_pixels(uint8_t seq, const uint8_t* p, size_t len) {
    if (len < 4) { send_error(MSG_SET_REEL_PIXELS, seq, ERR_BAD_PAYLOAD); return; }
    uint8_t  port  = p[0];
    uint16_t start = ((uint16_t)p[1] << 8) | p[2];
    uint8_t  cnt   = p[3];
    if (port >= cfg::N_PORTS) { send_error(MSG_SET_REEL_PIXELS, seq, ERR_REEL_ABSENT); return; }
    if (len < (size_t)(4 + cnt * 3)) { send_error(MSG_SET_REEL_PIXELS, seq, ERR_BAD_PAYLOAD); return; }
    reel_hw::stage_pixels(port, start, &p[4], cnt);
    send_ack(MSG_SET_REEL_PIXELS, seq);
}

static void handle_fill_reel(uint8_t seq, const uint8_t* p, size_t len) {
    if (len < 4) { send_error(MSG_FILL_REEL, seq, ERR_BAD_PAYLOAD); return; }
    uint8_t port = p[0];
    if (port >= cfg::N_PORTS) { send_error(MSG_FILL_REEL, seq, ERR_REEL_ABSENT); return; }
    reel_hw::stage_fill(port, p[1], p[2], p[3]);
    reel_hw::commit(1u << port);
    send_ack(MSG_FILL_REEL, seq);
}

static void handle_set_brightness(uint8_t seq, const uint8_t* p, size_t len) {
    if (len < 2) { send_error(MSG_SET_BRIGHTNESS, seq, ERR_BAD_PAYLOAD); return; }
    uint8_t port = p[0];
    if (port != REEL_ID_ALL && port >= cfg::N_PORTS) {
        send_error(MSG_SET_BRIGHTNESS, seq, ERR_REEL_ABSENT); return;
    }
    reel_hw::set_brightness(port, p[1]);
    uint8_t bitmap = (port == REEL_ID_ALL) ? ((1u << cfg::N_PORTS) - 1) : (1u << port);
    reel_hw::commit(bitmap);
    send_ack(MSG_SET_BRIGHTNESS, seq);
}

static void handle_commit(uint8_t seq, const uint8_t* p, size_t len) {
    uint8_t bitmap = (len >= 1) ? p[0] : ((1u << cfg::N_PORTS) - 1);
    reel_hw::commit(bitmap);
    send_ack(MSG_COMMIT, seq);
}

// =====================================================================
//  Firmware update receiver (arduino-pico OTA staging, validated)
// =====================================================================
static bool       s_fw_active   = false;
static bool       s_fw_verified = false;   // set only after a passing FW_VERIFY
static uint32_t   s_fw_total    = 0;
static uint32_t   s_fw_received = 0;
static sha256_ctx s_fw_sha;
static uint8_t    s_fw_expected[32];

static void handle_fw_begin(uint8_t seq, const uint8_t* p, size_t len) {
    if (len < 40) { send_error(MSG_FW_BEGIN, seq, ERR_BAD_PAYLOAD); return; }
    s_fw_total = be32(p);
    memcpy(s_fw_expected, p + 4, 32);
    uint32_t version = be32(p + 36);
    if (!Update.begin(s_fw_total, U_FLASH)) {
        Serial.printf("[fw] Update.begin failed (size=%lu)\n", (unsigned long)s_fw_total);
        send_error(MSG_FW_BEGIN, seq, ERR_BUSY);
        s_fw_active = false;
        return;
    }
    sha256_init(&s_fw_sha);
    s_fw_received = 0;
    s_fw_active   = true;
    s_fw_verified = false;
    Serial.printf("[fw] BEGIN size=%lu version=0x%08lX -- staging\n",
                  (unsigned long)s_fw_total, (unsigned long)version);
    send_ack(MSG_FW_BEGIN, seq);
}

static void handle_fw_chunk(uint8_t seq, const uint8_t* p, size_t len) {
    if (!s_fw_active || len < 4) { send_error(MSG_FW_CHUNK, seq, ERR_FW_STATE); return; }
    uint32_t offset = be32(p);
    const uint8_t* data = p + 4;
    size_t dlen = len - 4;
    if (offset == s_fw_received) {
        if (Update.write((uint8_t*)data, dlen) != dlen) {
            Serial.println("[fw] write failed");
            send_error(MSG_FW_CHUNK, seq, ERR_BUSY);
            return;
        }
        sha256_update(&s_fw_sha, data, dlen);
        s_fw_received += dlen;
    } else if (offset + dlen <= s_fw_received) {
        // already have it (retransmit) -- re-ACK
    } else {
        send_error(MSG_FW_CHUNK, seq, ERR_FW_OOR);
        return;
    }
    uint8_t ack[4]; put_be32(ack, s_fw_received);
    rs485_send(mk_response(MSG_FW_CHUNK), seq, ack, sizeof(ack));
}

static void handle_fw_verify(uint8_t seq) {
    if (!s_fw_active) { send_error(MSG_FW_VERIFY, seq, ERR_FW_STATE); return; }
    uint8_t got[32];
    sha256_ctx tmp = s_fw_sha;
    sha256_final(&tmp, got);
    if (s_fw_received != s_fw_total || memcmp(got, s_fw_expected, 32) != 0) {
        Serial.printf("[fw] VERIFY FAILED (received=%lu/%lu, hash %s)\n",
                      (unsigned long)s_fw_received, (unsigned long)s_fw_total,
                      memcmp(got, s_fw_expected, 32) ? "mismatch" : "ok");
        send_error(MSG_FW_VERIFY, seq, ERR_FW_HASH);
        return;
    }
    Serial.println("[fw] VERIFY ok");
    s_fw_verified = true;
    send_ack(MSG_FW_VERIFY, seq);
}

static void handle_fw_commit(uint8_t seq) {
    // Require a passing FW_VERIFY first: never flash an unhashed staged image,
    // even if a buggy/rogue host skips VERIFY and jumps straight to COMMIT.
    if (!s_fw_active || !s_fw_verified) { send_error(MSG_FW_COMMIT, seq, ERR_FW_STATE); return; }
    if (!Update.end(true)) {
        Serial.println("[fw] Update.end failed");
        send_error(MSG_FW_COMMIT, seq, ERR_BUSY);
        return;
    }
    s_fw_active   = false;
    s_fw_verified = false;
    Serial.println("[fw] COMMIT ok -- rebooting into new image");
    send_ack(MSG_FW_COMMIT, seq);
    delay(50);            // let the ACK flush onto the bus
    rp2040.reboot();      // OTA bootloader flashes the staged image
}

// =====================================================================
//  Frame dispatch
// =====================================================================
static void on_frame(uint8_t addr, uint8_t seq, uint8_t type,
                     const uint8_t* payload, size_t payload_len,
                     void* /*user*/) {
    if (addr != ADDR_CORE) return;
    if (is_response(type))  return;
    s_rx_frames++;
    s_last_master_ms = millis();

    switch (type) {
        case MSG_PING:          send_ack(MSG_PING, seq);                 break;
        case MSG_GET_VERSION:   handle_get_version(seq);                 break;
        case MSG_GET_STATUS:    handle_get_status(seq);                  break;
        case MSG_POLL:          handle_poll(seq);                        break;
        case MSG_ACK_EVENTS:    handle_ack_events(seq, payload, payload_len); break;
        case MSG_RESET: {
            uint8_t reason = payload_len ? payload[0] : 0;
            Serial.printf("[rs485] RESET reason=%u\n", reason);
            send_ack(MSG_RESET, seq);
            if (reason == 0) { delay(50); rp2040.reboot(); }
            // reason 1 (enter_update_mode): app handles FW_* live, no reboot.
            break;
        }
        case MSG_GET_REEL_INFO: handle_get_reel_info(seq, payload, payload_len); break;
        case MSG_READ_INPUTS:   handle_read_inputs(seq, payload, payload_len);   break;
        case MSG_SET_POLL_RATE: send_ack(MSG_SET_POLL_RATE, seq);        break;  // fixed-rate sampler
        case MSG_SET_REEL_PIXELS: handle_set_reel_pixels(seq, payload, payload_len); break;
        case MSG_FILL_REEL:       handle_fill_reel(seq, payload, payload_len);       break;
        case MSG_SET_BRIGHTNESS:  handle_set_brightness(seq, payload, payload_len);  break;
        case MSG_SET_ANIMATION:   send_ack(MSG_SET_ANIMATION, seq);      break;  // deferred (ACK only)
        case MSG_COMMIT:          handle_commit(seq, payload, payload_len);          break;
        case MSG_FW_BEGIN:        handle_fw_begin(seq, payload, payload_len);  break;
        case MSG_FW_CHUNK:        handle_fw_chunk(seq, payload, payload_len);  break;
        case MSG_FW_VERIFY:       handle_fw_verify(seq);                       break;
        case MSG_FW_COMMIT:       handle_fw_commit(seq);                       break;
        default:
            Serial.printf("[rs485] unknown cmd 0x%02X\n", type);
            send_error(type, seq, ERR_UNKNOWN_CMD);
            break;
    }
}

static Decoder* s_decoder = nullptr;

// =====================================================================
//  USB diagnostic console
// =====================================================================
static void print_help() {
    Serial.println(F(
        "\nSmartReel Core (production) -- diagnostic console:\n"
        "  help              this text\n"
        "  ver               firmware version\n"
        "  status            per-port module count / sense / inputs\n"
        "  stats             RS485 frame counters + link state\n"
        "  scan              force a sense + input sample now\n"
        "  on  <port> <hex>  fill a port's LEDs 0xRRGGBB (port 0-3) + show\n"
        "  off [port]        all LEDs off, or one port\n"
        "  bright <port|255> <0-255>  set brightness (255 = all)\n"
        "Reel inputs/sense are driven by real hardware; the HMI is the\n"
        "RS485 master. Numbers accept 0x.. hex or decimal."));
}

static long tok_num(const char* t, long def) {
    if (!t || !*t) return def;
    return strtol(t, nullptr, 0);
}

static void print_status() {
    Serial.printf("uptime=%lus  present=0x%02X  errflags=0x%04X  ads=%s\n",
                  (unsigned long)((millis() - s_boot_ms) / 1000),
                  reel_hw::reels_present_bitmap(), s_error_flags,
                  reel_hw::ads_ok() ? "ok" : "MISSING");
    for (uint8_t p = 0; p < cfg::N_PORTS; ++p) {
        const reel_hw::PortState& st = reel_hw::port(p);
        Serial.printf("  port %u: %u module(s)  sense=%4u mV", p, st.module_count, st.sense_mv);
        for (uint8_t m = 0; m < st.module_count; ++m)
            Serial.printf("  m%u=0x%08lX", m, (unsigned long)st.inputs[m]);
        Serial.println();
    }
    int pending = 0;
    for (int i = 0; i < EVT_RING; ++i) if (s_evt[i].used) pending++;
    Serial.printf("  pending (un-ACKed) events: %d\n", pending);
}
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
void loop() {
    // 1. Service the RS485 link first -- replies sent inline from on_frame().
    while (RS485.available()) {
        s_rx_bytes++;
        decoder_feed(s_decoder, (uint8_t)RS485.read());
    }
    poll_console();

    // 2. Hardware sampling -- suspended during a firmware update (flash
    //    writes disable XIP/interrupts; the bus is exclusive anyway).
    if (!s_fw_active) {
        uint32_t now = millis();
        static uint32_t last_in = 0, last_sense = 0;
        if (now - last_in >= cfg::INPUT_SAMPLE_MS)   { last_in = now;    reel_hw::sample_inputs(); }
        if (now - last_sense >= cfg::SENSE_SAMPLE_MS) { last_sense = now; reel_hw::sample_sense();  }
    }

    // 3. Debug LEDs.
    update_debug_leds();
}

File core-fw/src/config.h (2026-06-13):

// =====================================================================
//  SmartReel Core -- production firmware configuration
//
//  Pin map and hardware tunables for the Core PCB (RP2040). The pin
//  assignments here match the bring-up test (core-hwtest) verbatim --
//  that test confirmed all three slot subsystems on real hardware.
//
//  Hardware model
//  --------------
//  Four PORTS (0..3), each a physical connector on the Core PCB:
//      - one WS2812B data line          (GP6/7/8/9)
//      - one ADS1115 sense channel       (AIN0..3)
//      - one 74HC165 shift chain DIN     (GP12/13/14/15)
//        with SHARED clock (GP10) + latch (GP11)
//
//  Each port carries one or more chained reel MODULES. A module is a
//  pluggable strip of 16 reel-slots + 16 dividers:
//      - 16 WS2812B LEDs   (so a port's LED chain = 16 * n_modules)
//      - 32 input bits      (four 74HC165s; port chain = 32 * n_modules,
//        interleaved divider/slot: D0 S0 D1 S1 ... D15 S15)
//
//  The number of modules on a port is sensed from a voltage divider:
//  a 2.2k pull-up to 3.3V, plus a 10k pull-down per inserted module (so
//  n modules present 10k/n in parallel). See module_count_from_mv().
// =====================================================================
#pragma once

#include <stdint.h>

namespace cfg {

// ---- Port topology -------------------------------------------------
static constexpr uint8_t  N_PORTS            = 4;
static constexpr uint8_t  PORT_ALL           = 0xFF;   // "all ports" sentinel (matches rs485::REEL_ID_ALL)
static constexpr uint8_t  MODULE_LEDS        = 16;   // WS2812B per module
static constexpr uint8_t  MODULE_INPUT_BITS  = 32;   // 74HC165 bits per module
static constexpr uint8_t  MAX_MODULES_PER_PORT = 4;  // ADC divider resolution ceiling

static constexpr uint16_t MAX_PIXELS_PER_PORT = MODULE_LEDS * MAX_MODULES_PER_PORT;       // 64
static constexpr uint16_t MAX_BITS_PER_PORT   = MODULE_INPUT_BITS * MAX_MODULES_PER_PORT; // 128

// ---- WS2812B (one data line per port) ------------------------------
// NeoPXL8 needs all 8 pins within an 8-pin window; 6..9 qualifies.
// Unused outputs are -1. Index order = port 0..3.
static constexpr int8_t   LED_PINS[8]   = { 6, 7, 8, 9, -1, -1, -1, -1 };
static constexpr uint8_t  LED_BRIGHTNESS_DEFAULT = 64;   // 0-255, global

// ---- 74HC165 PISO (shared clock + latch, one DIN per port) ---------
static constexpr uint8_t  SR_DIN[N_PORTS] = { 12, 13, 14, 15 };
static constexpr uint8_t  SR_SCK   = 10;   // shared shift clock  (74HC165 CP)
static constexpr uint8_t  SR_LATCH = 11;   // shared parallel load (74HC165 PL#, active LOW)

// ---- ADS1115 reel-sense ADC ----------------------------------------
static constexpr uint8_t  I2C_SDA  = 0;    // I2C0 -> ADS1115
static constexpr uint8_t  I2C_SCL  = 1;
static constexpr uint8_t  ADS_ADDR = 0x48; // ADDR pin -> GND

// Sense divider component values. Rail = 3.3V * Rpd / (Rpd + RPULLUP),
// where Rpd = RMODULE / n_modules (pull-downs in parallel).
static constexpr float    SENSE_VREF_MV  = 3300.0f;
static constexpr float    SENSE_RPULLUP  = 2200.0f;   // ohms
static constexpr float    SENSE_RMODULE  = 10000.0f;  // ohms, per module

// ---- RS485 link ----------------------------------------------------
static constexpr uint8_t  PIN_RS485_TX = 16;   // -> SP3485 DI
static constexpr uint8_t  PIN_RS485_RX = 17;   // <- SP3485 RO
static constexpr uint8_t  PIN_RS485_DE = 18;   // -> SP3485 DE + RE#
// 115200 to match the HMI's auto-direction transceiver (can't turn
// around fast enough for higher rates). See esp32-hmi RS485 notes.
static constexpr uint32_t RS485_BAUD   = 115200;

// ---- Debug LEDs (discrete, on the Core PCB) ------------------------
static constexpr uint8_t  PIN_DBG_LINK = 2;    // RS485 link health
static constexpr uint8_t  PIN_DBG_AUX  = 3;    // spare / activity blip

// ---- Timing --------------------------------------------------------
// Button sampling: comfortably above the >5 Hz floor. 100 Hz gives
// ~10 ms input latency and leaves the bus + LEDs plenty of headroom.
static constexpr uint32_t INPUT_SAMPLE_HZ   = 100;
static constexpr uint32_t INPUT_SAMPLE_MS   = 1000 / INPUT_SAMPLE_HZ;
// A change must persist this many consecutive samples to count (debounce).
static constexpr uint8_t  INPUT_DEBOUNCE_SAMPLES = 2;

// Sense sampling is slow (ADS1115 conversions) and presence changes
// are slow too -- round-robin one channel per tick at ~10 Hz/channel.
static constexpr uint32_t SENSE_SAMPLE_MS   = 25;   // per-channel step; 4 ch -> 10 Hz each

// RS485 link is "up" if a valid master frame arrived within this window.
static constexpr uint32_t LINK_TIMEOUT_MS   = 1000;
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

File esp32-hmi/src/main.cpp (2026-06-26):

// =====================================================================
//  Reel Rack HMI -- entry point.
//
//  Bring-up order matters:
//    1) Wire (I2C)         -- so the CH422G expander can answer.
//    2) CH422G              -- everything below it (LCD, touch) needs
//                              the expander's reset / backlight pins.
//    3) RGB display + LVGL  -- the framebuffer is the heaviest user
//                              of PSRAM, do this before allocating
//                              any large UI structures.
//    4) GT911 touch         -- registers an LVGL input device.
//    5) SD card             -- best-effort; the UI shows a "NO SD"
//                              warning pill if the card is missing.
//    6) Config store        -- reads /sdcard/config.json + rack.json,
//                              applies to app_state.
//    7) UI                  -- theme, screen manager.
//    8) WiFi manager        -- non-blocking; starts a connection
//                              attempt if credentials are present.
//    9) RS485 master        -- UART1 in half-duplex mode; starts the
//                              background POLL task that pulls async
//                              events off the Core PCB.
// =====================================================================

#include <Arduino.h>
#include <Wire.h>
#include <lvgl.h>

#include "board/board_pins.h"
#include "board/ch422g.h"
#include "board/i2c_bus.h"
#include "display/display.h"
#include "touch/gt911.h"
#include "storage/sdcard.h"
#include "storage/config_store.h"
#include "storage/state_store.h"
#include "net/wifi_mgr.h"
#include "net/inv_api.h"
#include "rs485/rs485.h"
#include "fw/fw_update.h"
#include "fw/fw_core_update.h"
#include "sensors/qr_scanner.h"
#include "util/lvgl_async.h"
#include "ui/anomaly_modal.h"
#include "ui/status_bar.h"

#include <new>
#include <string.h>

#include "esp_system.h"
#include "soc/rtc_cntl_reg.h"

#include "ui/theme.h"
#include "ui/app_state.h"
#include "ui/status_bar.h"
#include "ui/screen_manager.h"
#include "ui/screens/screens.h"
#include "app/hw_mirror.h"
#include "app/slot_map.h"
#include "app/leds.h"
#include "app/beeper.h"
#include "app/inv_sync.h"
#include "ui/notify.h"

// ===================================================================
// Serial console.
//
// Tiny line-buffered reader on USB serial. Lets us trigger a reboot
// into UART download mode from a running firmware — no more juggling
// BOOT / RESET on the back of the board. The next esptool upload
// succeeds without any button presses.
// ===================================================================

static void enter_download_mode() {
    Serial.println("[console] rebooting into UART download mode...");
    Serial.flush();
    delay(50);
    // RTC_CNTL_FORCE_DOWNLOAD_BOOT (bit 0). On the next reset the ROM
    // bootloader checks this and enters UART download mode as if BOOT
    // were held. Cleared by the bootloader on entry, so this is a
    // one-shot — a subsequent normal reset boots the app again.
    REG_WRITE(RTC_CNTL_OPTION1_REG, 0x1);
    esp_restart();
}

static void handle_console_line(const char* line) {
    if (!*line) return;
    if (!strcmp(line, "dl") || !strcmp(line, "bootloader") ||
        !strcmp(line, "download")) {
        enter_download_mode();
        return;
    }
    if (!strcmp(line, "reboot") || !strcmp(line, "reset")) {
        Serial.println("[console] rebooting...");
        Serial.flush();
        delay(50);
        esp_restart();
        return;
    }
    if (!strcmp(line, "stats")) {
        const rs485::Stats& s = rs485::stats();
        Serial.printf("[rs485] tx=%lu rx=%lu crc_err=%lu timeouts=%lu retries=%lu events=%lu\n",
                      (unsigned long)s.tx_frames, (unsigned long)s.rx_frames,
                      (unsigned long)s.crc_errors, (unsigned long)s.timeouts,
                      (unsigned long)s.retries, (unsigned long)s.events_received);
        return;
    }
    if (!strcmp(line, "listen")) {
        uint8_t sample[32]; size_t sn = 0;
        size_t n = rs485::debug_raw_listen(1000, sample, sizeof(sample), &sn);
        Serial.printf("[rs485] listen 1000ms: %u raw bytes; sample:", (unsigned)n);
        for (size_t i = 0; i < sn; ++i) Serial.printf(" %02X", sample[i]);
        Serial.println();
        return;
    }
    if (!strcmp(line, "ping")) {
        rs485::Status st = rs485::ping();
        Serial.printf("[rs485] ping -> %s\n", rs485::status_str(st));
        return;
    }
    if (!strcmp(line, "scan")) {
        // The scanner worker re-probes 0x0C every ~200 ms, so present() is
        // live (<=200 ms stale) and reading it here needs no cross-thread
        // I2C. Lets you tell "gone" (no ACK) from "present but seeing no
        // code". Both reads are off the bus -- the worker owns I2C.
        if (!qr_scanner::present()) {
            Serial.println("[scan] NOT present on I2C 0x0C (no ACK) -- check wiring/power");
            return;
        }
        char b[256];
        if (qr_scanner::poll(b, sizeof(b)))
            Serial.printf("[scan] present; code in view: '%s'\n", b);
        else
            Serial.println("[scan] present (ACK ok); no decodable code in view");
        return;
    }
    if (!strcmp(line, "fwinfo")) {
        Serial.printf("[fw] HMI v%s  built %s  partition=%s  (git %s)\n",
                      fw::version_str(), fw::build_str(),
                      fw::running_partition_label(), fw::running_app_version());
        return;
    }
    if (!strncmp(line, "fwupdate", 8)) {
        char tmp[96];
        strncpy(tmp, line, sizeof(tmp) - 1); tmp[sizeof(tmp) - 1] = 0;
        strtok(tmp, " ");                       // "fwupdate"
        const char* target = strtok(nullptr, " ");
        const char* file   = strtok(nullptr, " ");
        if (!target || !file) {
            Serial.println("[fw] usage: fwupdate hmi <file> | fwupdate core <file>");
            return;
        }
        if (!strcmp(target, "hmi")) {
            Serial.printf("[fw] updating HMI from /sdcard/%s ...\n", file);
            fw::Result r = fw::update_hmi_from_sd(file, [](size_t d, size_t t) {
                static int last = -1;
                int pct = t ? (int)(100 * d / t) : 0;
                if (pct != last && pct % 10 == 0) { Serial.printf("[fw]  %d%%\n", pct); last = pct; }
            });
            if (r == fw::Result::Ok) {
                Serial.println("[fw] staged ok -- rebooting into new image");
                Serial.flush(); delay(100); esp_restart();
            } else {
                Serial.printf("[fw] FAILED: %s (running app unchanged)\n", fw::result_str(r));
            }
        } else if (!strcmp(target, "core")) {
            Serial.printf("[fw] pushing /sdcard/%s to RP2040 over RS485 ...\n", file);
            fw::CoreResult r = fw::update_core_from_sd(file, [](size_t d, size_t t) {
                static int last = -1;
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

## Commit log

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2026-05-18 Add ESP32 HMI firmware + docs/known-bugs.md
    esp32-hmi/
    Port of the standalone ESP32Display work tree as of idf5-port @ 8f3e507.
    Targets the Waveshare ESP32-S3-Touch-LCD-4.3B via pioarduino
    (arduino-esp32 3.2.1 / ESP-IDF 5.3).
    Highlights:
    - 800x480 RGB LCD with bounce buffer + double FB (proper tearing fix)
    - GT911 capacitive touch via I2C
    - CH422G I/O expander for LCD reset/backlight + touch reset
    - SDMMC 1-bit mode with auto-format-on-mount-fail and an explicit
    Format SD button on the Self Test screen
    - JSON config store (ArduinoJson v7) on /sdcard/config.json + rack.json
    - Live WiFi: scan list, password modal with on-screen keyboard,
    credential persist to SD, s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
    [board_pins.h, ch422g.cpp]
2026-05-18 ESP32: RS485 master implementation (protocol per docs/)
    Implements the SmartReel RS485 protocol from docs/smartreel-rs485-protocol.md
    on the ESP32 HMI side (bus master). The RP2040 Core side will be a
    companion implementation that uses the same proto.h.
    esp32-hmi/src/rs485/
    crc16.[h,cpp] CRC-16/CCITT-FALSE (poly 0x1021, init 0xFFFF) with
    a streaming-update variant for chunked use.
    rs485_proto.h Shared wire-format constants -- framing limits,
    addresses, type-bit conventions, message catalog
    (system / reel I/O / LEDs / async events / FW
    update), error codes, tunables. Header-only and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
    [board_pins.h, main.cpp, rs485.cpp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]
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2026-05-19 roadmap: flag auto-format-on-mount-failure for removal
    The current sdcard::init() passes format_if_mount_failed=true so a
    card with an unknown filesystem auto-formats. Convenient during
    bring-up but risky in production: a slightly corrupt FAT looks
    identical to "unknown format" from the IDF's point of view, so a bad
    sector or a flipped bit could trigger a silent wipe of the user's
    config + state. Phase 4 should flip this default to false; the
    explicit "Format SD card" button on Self Test stays as the user-
    visible path.
2026-05-25 ESP32 HMI: fix scrolling-list tearing via full-refresh + vsync swap
    Adopt Waveshare's canonical AVOID_TEARING_MODE 1 from the 4.3B
    reference (Arduino/examples/09_lvgl_Porting):
    - Drop the two PSRAM-allocated 40-line partial draw buffers.
    - Pull the two driver-managed framebuffer pointers out of the
    panel via esp_lcd_rgb_panel_get_frame_buffer(panel, 2, &fb0, &fb1)
    and hand them to LVGL as its draw_buf.
    - Switch LVGL to full_refresh mode so it always renders the whole
    screen into the inactive FB before flushing.
    - flush_cb calls esp_lcd_panel_draw_bitmap(0,0,W,H, fb); the IDF
    driver recognises the pointer matches a known FB and queues a
    swap for the next vsync (no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
    [display.cpp]
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2026-05-25 ESP32 HMI: tighten QR-scanner screen to stop tearing on poll
    The v1 QR screen called lv_obj_clean(log_container) + recreated all
    8 log rows on every fresh scan, and lv_label_set_text on the status
    label every 200 ms (the lv_timer tick). In full_refresh display mode
    each LVGL invalidation triggers a 768 KB write to PSRAM (back FB),
    and the resulting PSRAM contention starves the LCD DMA's bounce
    buffer -- visible as tearing while the user is on the QR screen.
    Three changes drop the LVGL invalidation rate to ~once per second:
    - Pre-create the LOG_MAX = 8 log rows once on screen build. On a
    new scan, just update each row's label text in place and toggle
    LV_OBJ_FLAG_HIDDEN. No allocat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
    [qr_scanner.cpp]
2026-05-25 ESP32 HMI: switch LVGL to direct_mode (AVOID_TEARING_MODE 3)
    Drops full_refresh: most LVGL updates now redraw only the dirty rect,
    not the whole 768 KB framebuffer. A once-per-second status-label
    update used to cost a full-screen render (and the resulting PSRAM
    burst was starving the LCD DMA bounce buffer); now it costs ~a few
    hundred pixels.
    Algorithm (per Waveshare reference, simplified):
    - LVGL writes each dirty rect directly into the active FB (one of
    the two driver-managed FBs handed in via lv_disp_draw_buf_init).
    - flush_cb accumulates the rects in s_dirty[] across the refresh.
    - On the last rect of a refresh (lv_disp_flush_is_last):
    1. esp_lcd_panel_draw_bitmap with f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
    [display.cpp]
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2026-05-26 ESP32 HMI: Phase 1 RS485 <-> UI plumbing + handoff doc
    main.cpp
    Replaces the stub RS485 event handler with a real dispatcher.
    EVT_INPUT_CHANGE parses both 7B (single-PISO, 8 inputs/reel) and
    9B (chained-PISO, 16 inputs/reel) payload shapes, heap-allocates
    an InputChangeEvent, and ui::dispatch_on_lvgl()s apply_input_change
    onto the LVGL task. The handler walks each changed bit, classifies
    the transition as expected (pick workflow removing a target slot;
    load workflow filling a target slot) vs unexpected (everything
    else), mutates app_state under app::lock(), marks dirty for the
    writer task, and raises the anomaly modal on unexpected changes.
    EVT_REEL_INSERTED/REMOVED/SENSE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
    [main.cpp]
2026-05-26 ESP32 HMI: serial console with 'dl' to enter UART download mode
    Tiny line-buffered reader polled from loop(). Sets
    RTC_CNTL_FORCE_DOWNLOAD_BOOT (one-shot, cleared by the ROM
    bootloader on entry) and esp_restart()s -- the next esptool upload
    goes through without BOOT/RESET juggling.
    Commands: dl|bootloader|download, reboot|reset, help|?.
    [main.cpp]
2026-05-26 RP2040 core test rig + HMI RS485 fixes: link validated end-to-end
    Add core-fw/: RP2040 firmware that implements the RS485 slave side of
    docs/smartreel-rs485-protocol.md (PING/GET_VERSION/GET_STATUS/POLL/reel
    I/O/LED ack + an event queue) so the HMI's RS485 master + UI plumbing can
    be exercised with no reel hardware. Fake reel events are injected from a
    USB-serial console (insert/remove/press/input/sense/log). Shares the wire
    codec with the HMI verbatim via a src/rs485 -> ../../esp32-hmi/src/rs485
    symlink (compiles crc16 + rs485_frame, excludes the ESP-IDF master).
    Add esp32-rs485-pintest/: standalone GPIO toggle tool used to bring the
    link up on the bench.
    HMI RS485 fixes found while bring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
    [board_pins.h, main.cpp, rs485.cpp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]
2026-05-26 tools/inject.py: host CLI to inject RS485 events + watch the HMI
    Auto-detects the RP2040 core (USB VID 2e8a) and ESP32 HMI (303a) so it's
    immune to /dev/ttyACM* swaps. Forwards event commands to the core console
    (insert/remove/press/input/sense/log) and tails the HMI's serial so the
    round trip is visible in one place; for INPUT_CHANGE (which the HMI does
    not log) it reports the HMI events-counter delta instead.
    One-shot (`inject.py insert 0 1650`) or interactive (no args). --list
    shows detected ports; --core/--hmi override; --no-hmi skips the tail.
    [inject.py]
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2026-05-27 RS485 firmware update for the RP2040 Core (FW update phase 2)
    End-to-end OTA: SD image -> ESP32 -> RS485 (SHA-256 verified) -> Core
    staged via arduino-pico OTA -> reboot into new image. Validated on
    hardware: a base build was pushed to v2 over the wire, the Core rebooted
    running v2, and the RS485 link stayed clean afterward.
    Protocol fix (rs485_proto.h, shared by both sides via symlink):
    FW_* messages were 0xF0+, but those are REQUEST types and 0xF0 has
    both the response (0x80) and error (0x40) framing bits set -- so the
    Core dropped them as "responses" and the master would read a reply as
    an "error". Renumbered to 0x30-0x35 (unused "config" request space).
    Core (core-fw):
    - plat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
    [_ctl.py, fw_core_update.h, main.cpp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]
2026-05-27 HMI: real firmware screen (versions + SD images + update buttons)
    Replace the mocked config_fwupdate screen with live data and working
    actions:
    - HMI card: running app version + active OTA partition, hmi.bin
    presence/size on SD, "Update HMI" (self-OTA from /sdcard/hmi.bin).
    - Core card: RP2040 version queried over RS485 (GET_VERSION), core.bin
    presence/size on SD, "Update Core" (push /sdcard/core.bin over RS485).
    Each action confirms, then runs on a one-shot worker task (the updates
    take seconds and must not block LVGL) showing a progress overlay driven
    via dispatch_on_lvgl. HMI update reboots into the new image; core update
    reports success/failure and refreshes the version read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
2026-05-27 Semantic firmware versions via an embedded image tag
    Replace the git-hash version readout with a real semver shown
    consistently for: the running HMI, the running Core (over RS485), and
    both update images sitting on the SD card.
    - fw_tag.h (shared, symlinked into core-fw): a magic-prefixed FwTag
    (major.minor.patch + project + build date) baked into .rodata of each
    image via FW_TAG_DEFINE. fw_tag_find() matches the magic with byte
    literals so the scanner doesn't emit a second copy of the magic into
    an image that both defines a tag and scans (the HMI).
    - Versions come from -DFW_VER_MAJOR/MINOR/PATCH in each platformio.ini
    (one place to bump per project).
    - HMI: version_str()/build_st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
    [main.cpp]
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2026-05-27 HMI firmware screen: do no blocking I/O on the LVGL thread
    The Firmware screen built with two blocking calls on the UI thread: a
    synchronous RS485 GET_VERSION and a multi-hundred-KB SD scan to read the
    update images' version tags. Both stalled the LVGL task during the
    screen build (worse if the Core was slow/absent), which could glitch the
    transition. The screen has no redraw timer -- this was the only UI-thread
    work.
    - Core version: the POLL task now caches GET_VERSION every ~5s
    (rs485::cached_version); the screen reads the cache, no transaction on
    the LVGL thread.
    - SD image versions: scanned on a one-shot worker task; the rows show
    size immediately + "checking...", then fill in via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
    [rs485.cpp, rs485.h]
2026-05-31 HMI: Load screen drives the real QR scanner against a SD parts catalog
    The Load screen used to wait on Simulate scan; now it free-runs the
    QR scanner at 5 Hz and latches the first recognised code into a new
    locked sub-state, exposing Rescan / Place reel / Cancel. The status
    line surfaces "no scanner on I2C", "watching", or "unrecognised code"
    in place of the static placeholder.
    QR labels resolve through a new parts_catalog module that reads
    /sdcard/parts.json into RAM at boot. The catalogue is the QR -> Part
    mapping the eventual InvenTree integration will replace; for now it's
    generated by scripts/gen_mock_qr.py alongside printable QR PNGs and a
    contact sheet, and copied to the SD by script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
    [main.cpp]
2026-06-01 HMI: inv_api client + editable network settings + scan-to-resolve
    Phase 1 of the InvenTree plugin integration. The HMI now talks to the
    mock-inventree server over HTTPS for the QR-scan flow; everything else
    keeps using local state until subsequent phases.
    net/inv_api (new): HTTPS-only client with /health, /barcode/resolve,
    and the slot/anomaly mutators. URL must start with https://; build_url
    and do_request both refuse plain http to keep the auth token off the
    wire in cleartext. Self-signed dev certs go through NetworkClientSecure
    ::setInsecure(); cert pinning to the mock's SHA-256 fingerprint is a
    follow-up. Every mutation accepts an op_id (chip-id + millis + counter)
    for server-side idemp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
    [main.cpp]
2026-06-01 HMI: pin inv_api workers to APP_CPU to stop RGB tearing
    The inv-resolve (load screen scan) and inv-health (network screen Test)
    worker tasks were pinned to PRO_CPU_NUM. PRO_CPU services the RGB LCD
    refresh DMA; main.cpp puts LVGL on APP_CPU specifically to keep PRO_CPU
    clear, and TLS handshake + JSON parse on PRO_CPU produces visible
    tearing while a worker runs.
    Move both to APP_CPU_NUM at priority 1 -- LVGL is also on APP_CPU at
    priority 2 so it still preempts. PRO_CPU is now user-code-free again.
2026-06-13 SmartReel: InvenTree integration (plugin + mock + HMI live workflows)
    End-to-end SmartReel<->InvenTree integration against docs/user-stories.md,
    plus the accumulated HMI/core working tree. Contract is canonical in
    docs/hmi-plugin-api.md (plugin + mock + HMI all speak it).
    InvenTree plugin (inventree-plugin/)
    Real plugin: /plugin/smartreel/api/v1/* (health, rack snapshot+register,
    barcode resolve, slot assign/pick/clear, pickjobs from BuildOrder
    metadata, anomaly log, provisioning QR). Whole-reel picks via
    StockItem.move(); Build Order "Send to SmartReel" panel + rack-location
    provisioning panel (static/panel.js). HMI_URL setting feeds the SRPROV1
    QR. test_live.py exercises the f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
    [SmartReelCore.kicad_pcb]
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2026-06-13 plugin: support multiple SmartReel racks (token-bound rack identity)
    One InvenTree instance now drives many independent racks. Each rack is a
    StockLocation tagged metadata['smartreel']={"is_rack":true,...}; the
    HMI's API token carries its rack (provisioning sets
    token.metadata['smartreel_rack']=<loc_pk>), so every rack-scoped request
    resolves its rack from request.auth — no HMI or wire-protocol change.
    - services.py: rack-scoped slot_map/snapshot/assign/pick/clear/locate/
    anomaly/jobs; rack_for_token(); per-rack staging/pulled with global
    default; list_rack_locations()/rack_info_list(); jobs store a target
    rack pk and filter by it.
    - api.py: SmartReelAPIView.rack(request) resolves +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
2026-06-14 HMI: fix LCD tearing (CPU pinning) + code-review fixes
    Tearing was CPU-core contention: tasks running on PRO_CPU (core 0) starved
    the RGB LCD DMA. Pin them to APP_CPU at priority 1, never PRO_CPU:
    - rs485-poll, state-writer: PRO_CPU_NUM -> APP_CPU_NUM (+ stale comment)
    - fw-upd, sd-ver: xTaskCreate -> xTaskCreatePinnedToCore(.., APP_CPU_NUM)
    Code-review fixes:
    - rs485: guard set_reel_pixels triple_count > 255 (1-byte wire field);
    move set_animation buffer to stack, document mutex invariant on the
    large static tx/payload buffers
    - inv_sync: widen app::lock() over apply_rack_result/apply_jobs_result
    shared-state reads (slot_by_num scans) to stop torn reads vs the
    state-writer snapshot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
    [main.cpp, rs485.cpp]
2026-06-14 plugin: add LocateMixin (locate-from-InvenTree) + concurrency fixes
    LocateMixin: the InvenTree web 'locate' button now lights the rack slot.
    The mixin runs in a background worker, so it only records intent: a
    locate is enqueued on the rack's metadata and surfaced to the HMI via
    the existing GET /rack poll (locates[]), drained by POST /rack/locates/ack.
    Mirrored in the mock (models/store/routes/seed/smoke-test) for testing.
    Code-review concurrency/atomicity fixes:
    - pick_job_item: wrap pick_slot + metadata writes in transaction.atomic()
    so a crash can't leave stock moved but the job marked unpicked
    - log_anomaly: transaction.atomic + select_for_update on the rack row to
    stop duplicate id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
2026-06-14 repo: reorganize into pcbs/ and debug-fw/, drop dead assets
    - pcbs/: CorePCB, ReelPCB
    - debug-fw/: mock-inventree, esp32-rs485-pintest, core-hwtest (untracked),
    inject.py (was tools/), sd-assets
    - sd-assets/parts.json removed: HMI resolves parts via InvenTree now, no SD
    catalog (main.cpp). gen_mock_qr.py no longer emits it; deploy-sd.sh no
    longer copies it. The mock QR codes stay (bench scan fixtures).
    - esp32-hmi/bump-fonts.sh removed (one-off dev script)
    - labels/: gitignore *.pdf and *.dxf (was the whole dir); track make_labels.py
    - flash-hwtest.sh / flash-pintest.sh point at debug-fw/
    - doc + comment path references updated to the new layout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
    [CAP-SMD_BD8.0-L8.3-W8.3-LS9.3-FD.step, CONN-TH_2P-P5.00_WJ500V-5.08-2P.step, CONN-TH_3P-P5.00_WJ500V-5.08-3P.step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]
2026-06-14 docs: add root README, prune obsolete session notes
    - README.md: top-level project overview, current layout, doc links, build/flash
    - remove four mid-development session-*.md notes superseded by the manual set
    - migrate the one durable nugget (jobs.json status not persisted across reboot)
    into known-bugs.md; fix the docs index's dangling session-file reference
2026-06-14 docs: drop roadmap, record cert-pinning gap, track core-hwtest
    - remove docs/roadmap.md (stale dev plan, superseded by the manual set)
    and its docs/README.md index entry
    - known-bugs.md: add the pre-ship TLS gap — HMI uses setInsecure(), the
    SRPROV1 fingerprint field is parsed but not enforced
    - test-plan.md: drop the obsolete 'load via offline SD catalog' step
    (HMI resolves parts via InvenTree now; no SD catalog)
    - inv_api.h: fix stale mock-inventree paths -> debug-fw/mock-inventree
    - track debug-fw/core-hwtest/ (platformio.ini + src), referenced by
    scripts/flash-hwtest.sh
    [main.cpp]
2026-06-15 HMI: implement review-feedback UI/UX fixes
    Firmware side of docs/review-feedback-solutions.md:
    - Add a beeper seam (app/beeper) wired to confirm/error/warn sites so
    the buzzer hardware (item 5) is a one-file change later.
    - Add a shared notify overlay (toast + confirm + interactive pick-prompt)
    reused across the confirmation items.
    - Nav: Rack is now a sub-page of View, not a Home tile (item 1).
    - Illegal removal flashes the slot red and tones (item 2); the inventory
    unload is no longer automatic -- it's gated behind an explicit confirm
    in the anomaly modal (item 3, the stock-loss bug).
    - Load: success confirmation (green flash + tone + toast, item 4);
    'Scan reel barcode' rename (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
    [main.cpp]
2026-06-16 items 6 & 21: fast occupancy poll; correct cross-instance load rule
    Item 6 (detect InvenTree-side moves within ~10s):
    - Plugin: GET /rack/occupancy returns a cheap occupancy fingerprint
    (services.occupancy_rev) over one query, folding in the locate queue.
    - HMI: inv_api::get_occupancy() + a 5s poll in inv_sync that triggers a
    full reconcile only when the fingerprint changes.
    Item 21 (cross-instance load), corrected per feedback: reject a reel
    already housed in THIS rack (existing slot_num>0 check), but ACCEPT reels
    from a different SmartReel -- loading transfers them, and the source rack
    notices via its occupancy poll (item 6). No cross-rack rejection.
    Builds clean (pio run); plugin pa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
2026-06-16 docs: add Round 2 review feedback + proposed solutions
    Post-implementation review of the Round 1 build (R1-R16): toast renders
    empty, scan-screen arrow, settings tearing, boot divider misread collapsing
    a port into one slot (+ resulting lost contents), illegal divider edits on
    occupied slots, home 2x2, full-width rack button, anomaly detail overlap,
    reel-replaced flow, View slot labels, remove Settings Exit, dead numbering
    UI, self-test single-slot Light.
2026-06-16 HMI: implement Round 2 review fixes
    - R1/R4: toast rendered as an empty rounded rectangle (label sized
    LV_PCT(100) in a content-sized box collapsed to 0 width) -> size to text.
    - R2: big left arrow + 'Scanner' on the scan-reel screen (scanner is left).
    - R5: boot input read could come back all-zero (Core not scanned yet),
    collapsing a whole port into one giant slot -> retry until real bits.
    - R6: rebuild_rack preserves contents by physical anchor, not just logical
    number, so a re-number doesn't drop a placed reel.
    - R7: divider edits bordering an OCCUPIED slot are refused (must unload
    first) regardless of commission state.
    - R8: Home is a 2x2 grid (Load/Pick top, View/Settings bottom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
    [main.cpp]
2026-06-26 R5: prime Core input state at module detection; drop HMI retry hack
    The boot all-zero read that collapsed a port into one giant slot is now
    fixed at the source. When a port's module count rises (boot or hot-insert),
    reel_hw::prime_inputs() seeds the debounce state from an immediate raw
    74HC165 scan, so READ_INPUTS reflects the true latched state right away
    instead of a pre-debounce zero.
    With the Core guaranteeing a correct first read, hw_mirror::sync_from_core
    drops the 5-attempt / delay(40) retry loop (and the now-unused
    <Arduino.h>) and does a single read_inputs() per present port. An all-zero
    word now correctly means a genuinely empty, divider-less module.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
    [reel_hw.cpp]
2026-06-26 HMI: drawn left scanner arrow + 'scan' console diagnostic
    - load: replace the font-glyph scanner cue with a drawn "<-" (arrowhead
    polyline + shaft) anchored to the left edge, vertically centred, scaled
    to ~70% length so it clears the centred scan text. Enables LV_USE_LINE.
    - console: add 'scan' command -- live re-probe of the QR reader on I2C
    0x0C plus one read, so a scanner that fell off the bus (no ACK) is
    distinguishable from one that's present but seeing no code.
    [main.cpp]
2026-06-26 HMI: reduce RGB-panel tearing on page changes (R3, fixes A.1+A.3)
    Tearing on page navigation is PSRAM-bandwidth starvation of the LCD
    scanout DMA, not a torn FB swap (the swap is vsync-gated). Two mitigations
    on the display path:
    - A.1: double the LCD bounce buffer (10 -> 20 scanlines) so it tolerates
    longer PSRAM-bus stalls before underflowing into a visible tear.
    - A.3: chunk flush_cb's post-swap dirty-rect copy. The copy reads the
    just-swapped front buffer while the DMA scans that same PSRAM out; a
    full-screen blit spikes bus demand for several ms. Tall rects now copy
    in 48-row bands with a ~1 ms yield between them so the DMA can refill
    the bounce buffer; small rects (status la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
    [display.cpp]
2026-06-26 HMI: move LED RS485 writes off the LVGL thread (review item B)
    leds:: calls used to push pixels + commit synchronously over RS485 -- a
    multi-ms blocking bus round-trip -- and run on the LVGL render thread
    (500 ms alarm-flash tick, slot-change/pick/load handlers), stalling
    lv_timer_handler and adding display jank.
    Now the public API only mutates an in-RAM shadow of the desired per-port
    LED state (cheap, on the caller's thread) and signals a worker. One task
    pinned to APP_CPU drains the shadow to the Core over RS485; rapid updates
    coalesce to the latest state rather than queueing. No caller inspected the
    return value, and light_slot keeps its synchronous invalid-slot check
    (R16), so behaviour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
    [main.cpp]
2026-06-26 HMI: move QR scanner I2C off the LVGL thread (review item B)
    The scanner read ran in an lv_timer on the LVGL thread -- a 256-byte
    blocking I2C transfer (several ms) every 200 ms, stalling the render loop.
    A worker task pinned to APP_CPU now owns all scanner I2C and latches the
    latest decoded code + live presence; poll()/present() just read the latch
    and never touch the bus, so the LVGL thread never blocks on the scanner.
    poll() keeps its free-running contract, so the screens are unchanged.
    Because touch (GT911), the CH422G expander, and the scanner now share the
    Wire bus across two threads, add a shared i2c_bus::Lock around every
    complete transaction (GT911's repeated-START reads must stay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
    [ch422g.cpp, gt911.cpp, main.cpp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]
2026-07-09 Publication prep: license, host tests, credential/env cleanup, review fixes
    - Add MIT LICENSE, project-status disclaimer in README, PUBLICATION-PREP.md tracker
    - New host-runnable tests: tests/ (RS485 frame codec) and inventree-plugin/test_services.py
    - Dev scripts and live tests: hardcoded credentials/paths -> env vars, internal
    hostnames -> placeholders, fix stale /provision call in set-hmi-url.sh
    - core-fw: require passing FW_VERIFY before FW_COMMIT (s_fw_verified gate)
    - HMI: marshal WiFi event online-state onto the LVGL task; unconfigured defaults
    - Plugin: bind token metadata inside the atomic block; lock rack row in enqueue_locate
    - Remove superseded review docs (review-feedback*, t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
    [main.cpp]
